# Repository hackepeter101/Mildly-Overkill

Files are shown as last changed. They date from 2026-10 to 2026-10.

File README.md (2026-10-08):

# Simple PLC-like Controller for Simple 24V Logic

## Specifications I am aiming for:

### Power & Protection
- 3S to 6S LiPo input support (including 24V)
- Onboard buck converter
- Reverse polarity protection
- Integrated fuse

### Motor Control
- 2x DC motor drivers (H-bridges)
- 3A current rating per bridge
- Current sensing at the H-bridges

### I/O & Interfaces
- Minimum of 8 total Inputs/Outputs (including H-bridge pins)
- STEMMA QT (I2C) connector
- USB-C port
- Physical Boot and Reset buttons

## Why
I have a project I need this for. I also did something similar for my day job and, to be honest, I wasn't entirely satisfied with my own work there—so this is my chance to improve on it.

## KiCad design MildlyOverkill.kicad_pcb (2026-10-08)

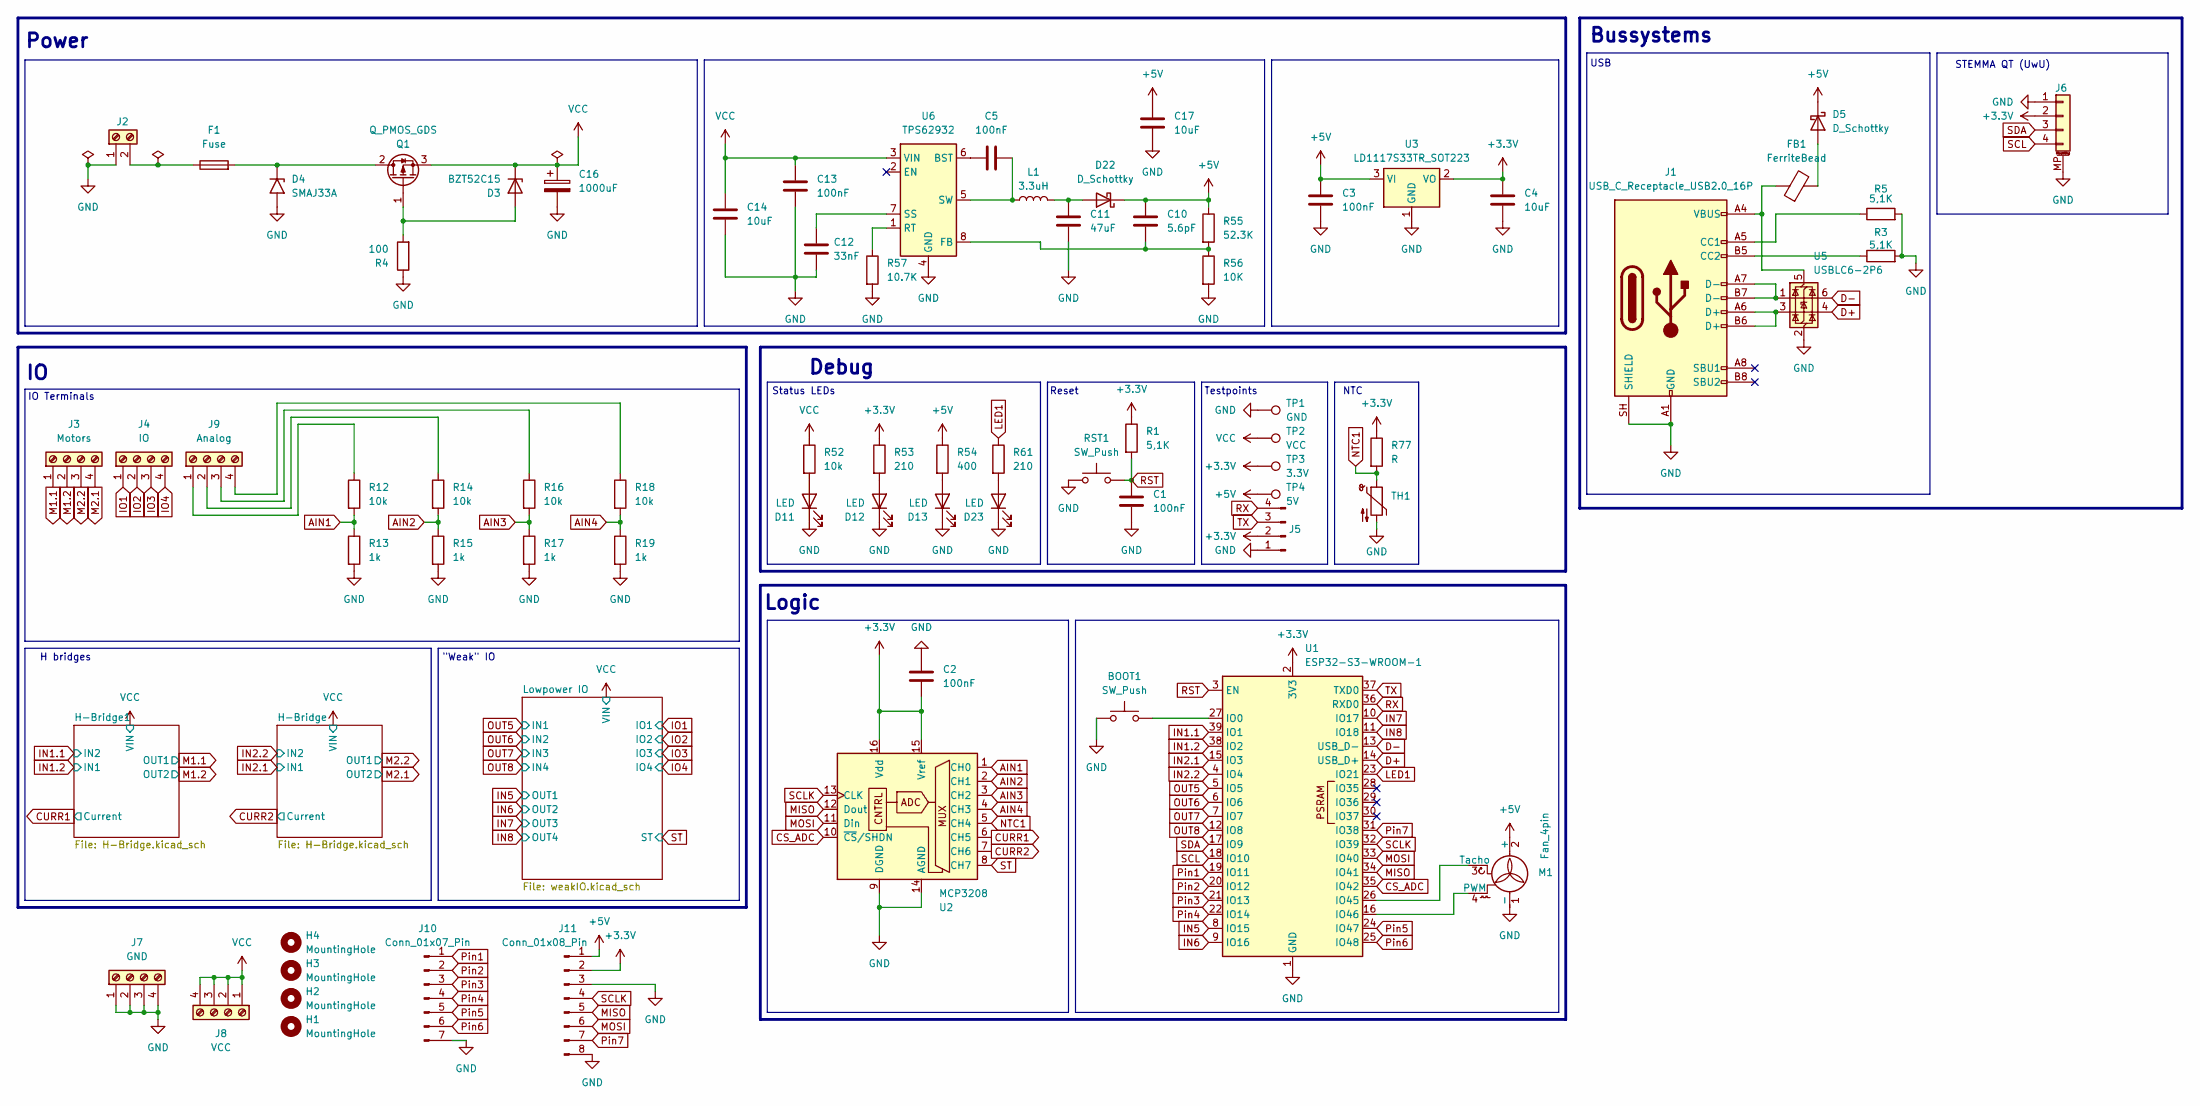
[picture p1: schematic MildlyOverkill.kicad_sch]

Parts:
BOOT1: SW_Push; SW_SPST_PTS647_Sx50
C1, C2, C3, C5, C13: 100nF; C_0603_1608Metric
C4: 10uF; C_1206_3216Metric
C10: 5.6pF; C_0603_1608Metric
C11: 47uF; C_0603_1608Metric
C12: 33nF; C_0603_1608Metric
C14: 10uF; C_1210_3225Metric
C16: 1000uF; CP_Radial_D16.0mm_P7.50mm
C17: 10uF; C_0603_1608Metric
D3: BZT52C15; D_0805_2012Metric
D4: SMAJ33A; D_SMA
D5, D22: D_Schottky; D_SOD-123
D11, D12, D13, D23: LED; LED_0603_1608Metric
F1: Fuse; Fuseholder_Blade_Mini_Keystone_3568
FB1: FerriteBead; L_0805_2012Metric
H1, H2, H3, H4: MountingHole; MountingHole_2.1mm
J1: USB_C_Receptacle_USB2.0_16P; USB_C_Receptacle_HRO_TYPE-C-31-M-12
J2: Screw_Terminal_01x02; PhoenixContact_MSTBA_2,5_2-G_1x02_P5.00mm_Horizontal
J3: Motors; TerminalBlock_Phoenix_MPT-0,5-4-2.54_1x04_P2.54mm_Horizontal
J4: IO; TerminalBlock_Phoenix_MPT-0,5-4-2.54_1x04_P2.54mm_Horizontal
J5: Conn_01x04_Pin; PinHeader_1x04_P2.54mm_Vertical
J6: Conn_01x04_MountingPin; JST_SH_BM04B-SRSS-TB_1x04-1MP_P1.00mm_Vertical
J7: GND; TerminalBlock_Phoenix_MPT-0,5-4-2.54_1x04_P2.54mm_Horizontal
J8: VCC; TerminalBlock_Phoenix_MPT-0,5-4-2.54_1x04_P2.54mm_Horizontal
J9: Analog; TerminalBlock_Phoenix_MPT-0,5-4-2.54_1x04_P2.54mm_Horizontal
J10: Conn_01x07_Pin; PinSocket_1x07_P2.54mm_Vertical
J11: Conn_01x08_Pin; PinSocket_1x08_P2.54mm_Vertical
L1: 3.3uH; WE-XHMI 4.3x4.3
M1: Fan_4pin; FanPinHeader_1x04_P2.54mm_Vertical
Q1: Q_PMOS_GDS; TO-252-2
R1, R3, R5: 5,1K; R_0603_1608Metric
R4: 100; R_0603_1608Metric
R12, R14, R16, R18, R52: 10k; R_0603_1608Metric
R13, R15, R17, R19: 1k; R_0603_1608Metric
R53, R61: 210; R_0603_1608Metric
R54: 400; R_0603_1608Metric
R55: 52.3K; R_0603_1608Metric
R56: 10K; R_0603_1608Metric
R57: 10.7K; R_0603_1608Metric
R77: R; R_0603_1608Metric
RST1: SW_Push; SW_SPST_PTS647_Sx50
TH1: Thermistor_NTC; R_0805_2012Metric_Pad1.20x1.40mm_HandSolder
TP1: GND; TestPoint_Loop_D2.50mm_Drill1.85mm
TP2: VCC; TestPoint_Loop_D2.50mm_Drill1.85mm
TP3: 3.3V; TestPoint_Loop_D2.50mm_Drill1.85mm
TP4: 5V; TestPoint_Loop_D2.50mm_Drill1.85mm
U1: ESP32-S3-WROOM-1
U2: MCP3208; SOIC-16_3.9x9.9mm_P1.27mm
U3: LD1117S33TR_SOT223; SOT-223-3_TabPin2
U5: USBLC6-2P6; SOT-666
U6: TPS62932; SOT-583-8

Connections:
+3.3V: C2.2, C4.1, J5.2, J6.2, J11.2, R1.1, R53.1, R77.1, TP3.1 (1_1), U1.2 (3V3), U2.15 (Vref), U2.16 (Vdd), U3.2 (VO); also elsewhere on the board
+5V: C3.1, C10.2, C17.2, D5.1 (K), D22.1 (K), J11.1, M1.2 (+), R54.1, R55.1, TP4.1 (1_1), U3.3 (VI)
AIN1: R12.2, R13.1, U2.1 (CH0)
AIN2: R14.2, R15.1, U2.2 (CH1)
AIN3: R16.2, R17.1, U2.3 (CH2)
AIN4: R18.2, R19.1, U2.4 (CH3)
CS_ADC: U1.35 (IO42), U2.10 (~CS/SHDN)
CURR1: U2.6 (CH5); also elsewhere on the board
CURR2: U2.7 (CH6); also elsewhere on the board
D+: U1.14 (USB_D+), U5.4 (I/O2)
D-: U1.13 (USB_D-), U5.6 (I/O1)
GND: BOOT1.1, C1.2, C2.1, C3.2, C4.2, C11.1, C12.1, C13.1, C14.1, C16.2, C17.1, D4.2 (A2), D11.1 (K), D12.1 (K), D13.1 (K), D23.1 (K), J1.A1 (GND), J1.A12 (GND), J1.B1 (GND), J1.B12 (GND), J1.SH (SHIELD), J2.1, J5.1, J6.1, J6.MP (MountPin), J7.1, J7.2, J7.3, J7.4, J10.7, J11.3, J11.8, M1.1 (-), R3.2, R4.1, R5.2, R13.2, R15.2, R17.2, R19.2, R56.2, R57.2, RST1.1, TH1.2, TP1.1 (1_1), U1.1 (GND), U1.40 (GND), U1.41 (GND), U2.9 (DGND), U2.14 (AGND), U3.1 (GND), U5.2 (GND), U6.4 (GND); also elsewhere on the board
IN1.1: U1.39 (IO1); also elsewhere on the board
IN1.2: U1.38 (IO2); also elsewhere on the board
IN2.1: U1.15 (IO3); also elsewhere on the board
IN2.2: U1.4 (IO4); also elsewhere on the board
IN5: U1.8 (IO15); also elsewhere on the board
IN6: U1.9 (IO16); also elsewhere on the board
IN7: U1.10 (IO17); also elsewhere on the board
IN8: U1.11 (IO18); also elsewhere on the board
IO1: J4.1; also elsewhere on the board
IO2: J4.2; also elsewhere on the board
IO3: J4.3; also elsewhere on the board
IO4: J4.4; also elsewhere on the board
LED1: R61.1, U1.23 (IO21)
M1.1: J3.1; also elsewhere on the board
M1.2: J3.2; also elsewhere on the board
M2.1: J3.4; also elsewhere on the board
M2.2: J3.3; also elsewhere on the board
MISO: J11.5, U1.34 (IO41), U2.12 (Dout)
MOSI: J11.6, U1.33 (IO40), U2.11 (Din)
NTC1: R77.2, TH1.1, U2.5 (CH4)
unnamed: D3.2 (A), Q1.1 (G), R4.2
unnamed: D4.1 (A1), F1.2, Q1.2 (D)
unnamed: D5.2 (A), FB1.2
unnamed: D11.2 (A), R52.2
unnamed: D12.2 (A), R53.2
unnamed: D13.2 (A), R54.2
unnamed: C11.2, D22.2 (A), L1.2
unnamed: D23.2 (A), R61.2
unnamed: J1.A5 (CC1), R5.1
unnamed: J1.B5 (CC2), R3.1
unnamed: J1.A6 (D+), J1.B6 (D+), U5.3 (I/O2)
unnamed: J1.A7 (D-), J1.B7 (D-), U5.1 (I/O1)
unnamed: F1.1, J2.2
unnamed: J9.1, R12.1
unnamed: J9.2, R14.1
unnamed: J9.3, R16.1
unnamed: J9.4, R18.1
unnamed: M1.4 (PWM), U1.16 (IO46)
unnamed: M1.3 (Tacho), U1.26 (IO45)
unnamed: BOOT1.2, U1.27 (IO0)
unnamed: FB1.1, J1.A4 (VBUS), J1.A9 (VBUS), J1.B4 (VBUS), J1.B9 (VBUS), U5.5 (VBUS)
unnamed: C5.1, U6.6 (BST)
unnamed: C10.1, R55.2, R56.1, U6.8 (FB)
unnamed: R57.1, U6.1 (RT)
unnamed: C12.2, U6.7 (SS)
unnamed: C5.2, L1.1, U6.5 (SW)
OUT5: U1.5 (IO5); also elsewhere on the board
OUT6: U1.6 (IO6); also elsewhere on the board
OUT7: U1.7 (IO7); also elsewhere on the board
OUT8: U1.12 (IO8); also elsewhere on the board
Pin1: J10.1, U1.19 (IO11)
Pin2: J10.2, U1.20 (IO12)
Pin3: J10.3, U1.21 (IO13)
Pin4: J10.4, U1.22 (IO14)
Pin5: J10.5, U1.24 (IO47)
Pin6: J10.6, U1.25 (IO48)
Pin7: J11.7, U1.31 (IO38)
RST: C1.1, R1.2, RST1.2, U1.3 (EN)
RX: J5.4, U1.36 (RXD0)
SCL: J6.4, U1.18 (IO10)
SCLK: J11.4, U1.32 (IO39), U2.13 (CLK)
SDA: J6.3, U1.17 (IO9)
ST: U2.8 (CH7); also elsewhere on the board
TX: J5.3, U1.37 (TXD0)
VCC: C13.2, C14.2, C16.1, D3.1 (K), J8.1, J8.2, J8.3, J8.4, Q1.3 (S), R52.1, TP2.1 (1_1), U6.3 (VIN); also elsewhere on the board

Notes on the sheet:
H bridges
Debug
IO Terminals
Power
Reset
NTC
Logic
Testpoints
STEMMA QT (UwU)
Bussystems
"Weak" IO
USB
Status LEDs

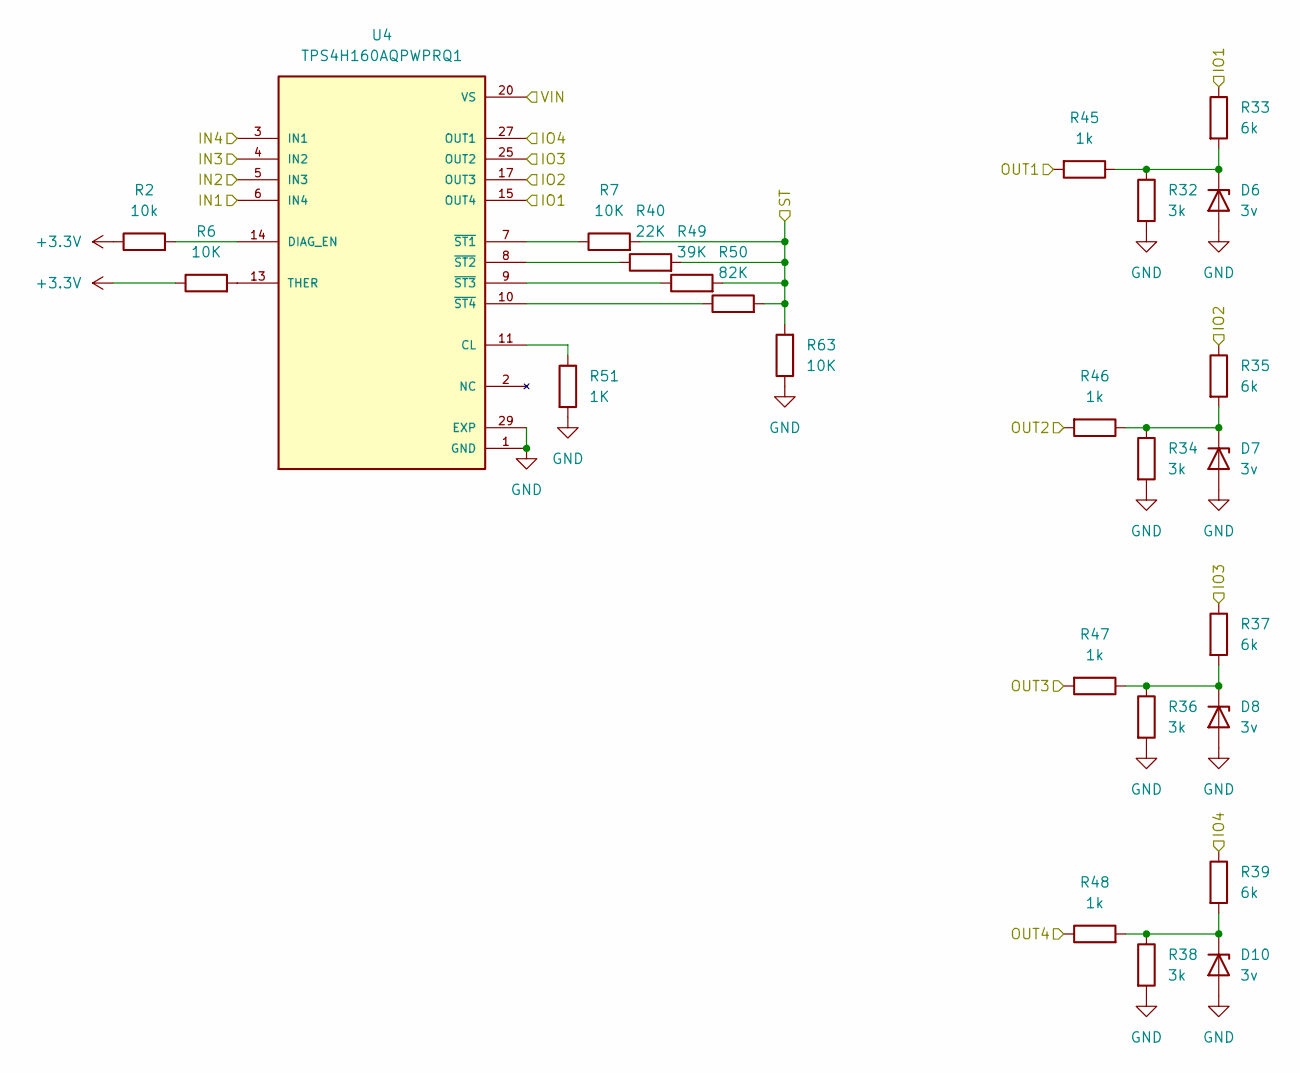
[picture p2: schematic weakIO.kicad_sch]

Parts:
D6, D7, D8, D10: 3v; D_0603_1608Metric
R2: 10k; R_0603_1608Metric
R6, R7, R63: 10K; R_0603_1608Metric
R32, R34, R36, R38: 3k; R_0603_1608Metric
R33, R35, R37, R39: 6k; R_0603_1608Metric
R40: 22K; R_0603_1608Metric
R45, R46, R47, R48: 1k; R_0603_1608Metric
R49: 39K; R_0603_1608Metric
R50: 82K; R_0603_1608Metric
R51: 1K; R_0603_1608Metric
U4: TPS4H160AQPWPRQ1; IC_TPS4H160AQPWPRQ1; PARTREV D

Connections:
+3.3V: R2.1, R6.1; also elsewhere on the board
GND: D6.2 (A), D7.2 (A), D8.2 (A), D10.2 (A), R32.2, R34.2, R36.2, R38.2, R51.2, R63.1, U4.1 (GND), U4.12 (GND), U4.29 (EXP), U4.30 (EXP), U4.31 (EXP), U4.32 (EXP), U4.33 (EXP), U4.34 (EXP), U4.35 (EXP), U4.36 (EXP), U4.37 (EXP), U4.38 (EXP), U4.39 (EXP), U4.40 (EXP), U4.41 (EXP), U4.42 (EXP), U4.43 (EXP), U4.44 (EXP), U4.45 (EXP), U4.46 (EXP), U4.47 (EXP), U4.48 (EXP), U4.49 (EXP), U4.50 (EXP), U4.51 (EXP), U4.52 (EXP), U4.53 (EXP); also elsewhere on the board
IN5: R45.2; also elsewhere on the board
IN6: R46.2; also elsewhere on the board
IN7: R47.2; also elsewhere on the board
IN8: R48.1; also elsewhere on the board
IO1: R33.1, U4.15 (OUT4), U4.16 (OUT4); also elsewhere on the board
IO2: R35.1, U4.17 (OUT3), U4.18 (OUT3); also elsewhere on the board
IO3: R37.1, U4.25 (OUT2), U4.26 (OUT2); also elsewhere on the board
IO4: R39.1, U4.27 (OUT1), U4.28 (OUT1); also elsewhere on the board
unnamed: D6.1 (K), R32.1, R33.2, R45.1
unnamed: D7.1 (K), R34.1, R35.2, R46.1
unnamed: D8.1 (K), R36.1, R37.2, R47.1
unnamed: D10.1 (K), R38.1, R39.2, R48.2
unnamed: R51.1, U4.11 (CL)
unnamed: R2.2, U4.14 (DIAG_EN)
unnamed: R6.2, U4.13 (THER)
unnamed: R7.1, U4.7 (~ST1)
unnamed: R40.1, U4.8 (~ST2)
unnamed: R49.1, U4.9 (~ST3)
unnamed: R50.1, U4.10 (~ST4)
OUT5: U4.6 (IN4); also elsewhere on the board
OUT6: U4.5 (IN3); also elsewhere on the board
OUT7: U4.4 (IN2); also elsewhere on the board
OUT8: U4.3 (IN1); also elsewhere on the board
ST: R7.2, R40.2, R49.2, R50.2, R63.2; also elsewhere on the board
VCC: U4.20 (VS), U4.21 (VS), U4.22 (VS), U4.23 (VS); also elsewhere on the board

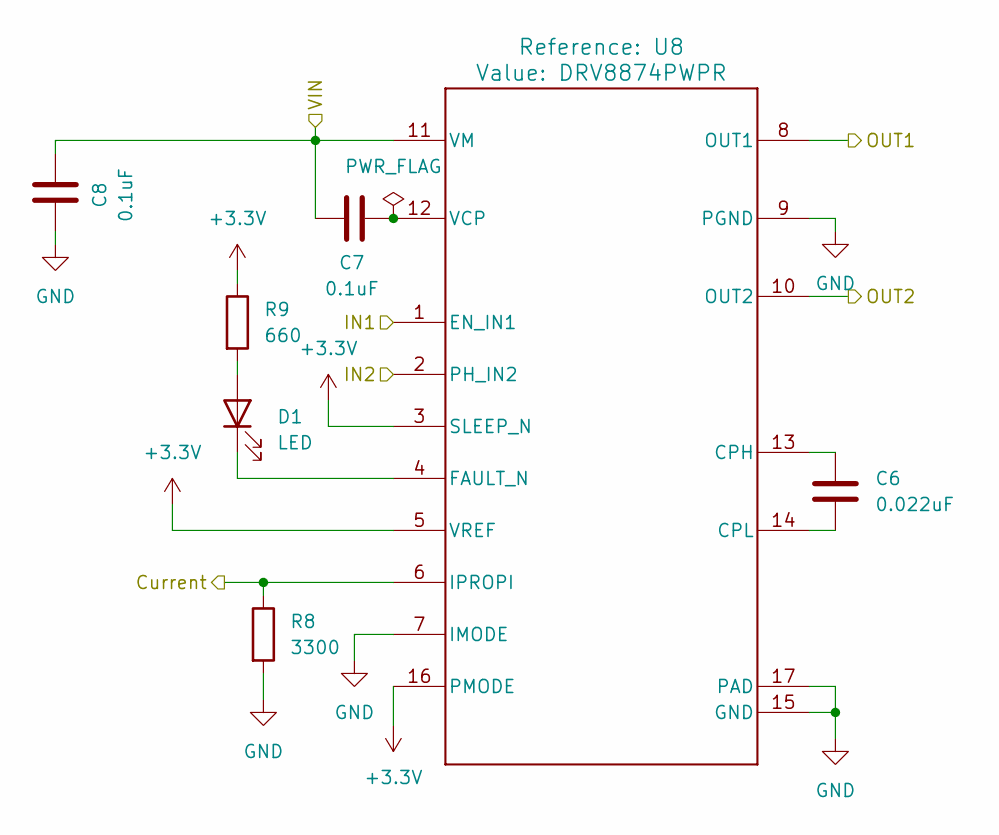
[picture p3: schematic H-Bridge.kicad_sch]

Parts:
C6: 0.022uF; C_0603_1608Metric
C7, C8: 0.1uF; C_0603_1608Metric
D1: LED; LED_0603_1608Metric
R8: 3300; R_0603_1608Metric
R9: 660; R_0603_1608Metric
U8: DRV8874PWPR; PWP0016J_L

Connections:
+3.3V: R9.1, U8.3 (SLEEP_N), U8.5 (VREF), U8.16 (PMODE); also elsewhere on the board
CURR2: R8.1, U8.6 (IPROPI); also elsewhere on the board
GND: C8.1, R8.2, U8.7 (IMODE), U8.9 (PGND), U8.15 (GND), U8.17 (PAD); also elsewhere on the board
IN2.1: U8.1 (EN_IN1); also elsewhere on the board
IN2.2: U8.2 (PH_IN2); also elsewhere on the board
M2.1: U8.10 (OUT2); also elsewhere on the board
M2.2: U8.8 (OUT1); also elsewhere on the board
unnamed: D1.2 (A), R9.2
unnamed: D1.1 (K), U8.4 (FAULT_N)
unnamed: C6.1, U8.13 (CPH)
unnamed: C6.2, U8.14 (CPL)
unnamed: C7.2, U8.12 (VCP)
VCC: C7.1, C8.2, U8.11 (VM); also elsewhere on the board

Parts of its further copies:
C9, C15: 0.1uF; C_0603_1608Metric
C18: 0.022uF; C_0603_1608Metric
D2: LED; LED_0603_1608Metric
R10: 660; R_0603_1608Metric
R11: 3300; R_0603_1608Metric
U9: DRV8874PWPR; PWP0016J_L

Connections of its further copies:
+3.3V: R10.1, U9.3 (SLEEP_N), U9.5 (VREF), U9.16 (PMODE); also elsewhere on the board
CURR1: R11.1, U9.6 (IPROPI); also elsewhere on the board
GND: C9.1, R11.2, U9.7 (IMODE), U9.9 (PGND), U9.15 (GND), U9.17 (PAD); also elsewhere on the board
IN1.1: U9.2 (PH_IN2); also elsewhere on the board
IN1.2: U9.1 (EN_IN1); also elsewhere on the board
M1.1: U9.8 (OUT1); also elsewhere on the board
M1.2: U9.10 (OUT2); also elsewhere on the board
unnamed: D2.2 (A), R10.2
unnamed: D2.1 (K), U9.4 (FAULT_N)
unnamed: C18.1, U9.13 (CPH)
unnamed: C18.2, U9.14 (CPL)
unnamed: C15.2, U9.12 (VCP)
VCC: C9.2, C15.1, U9.11 (VM); also elsewhere on the board

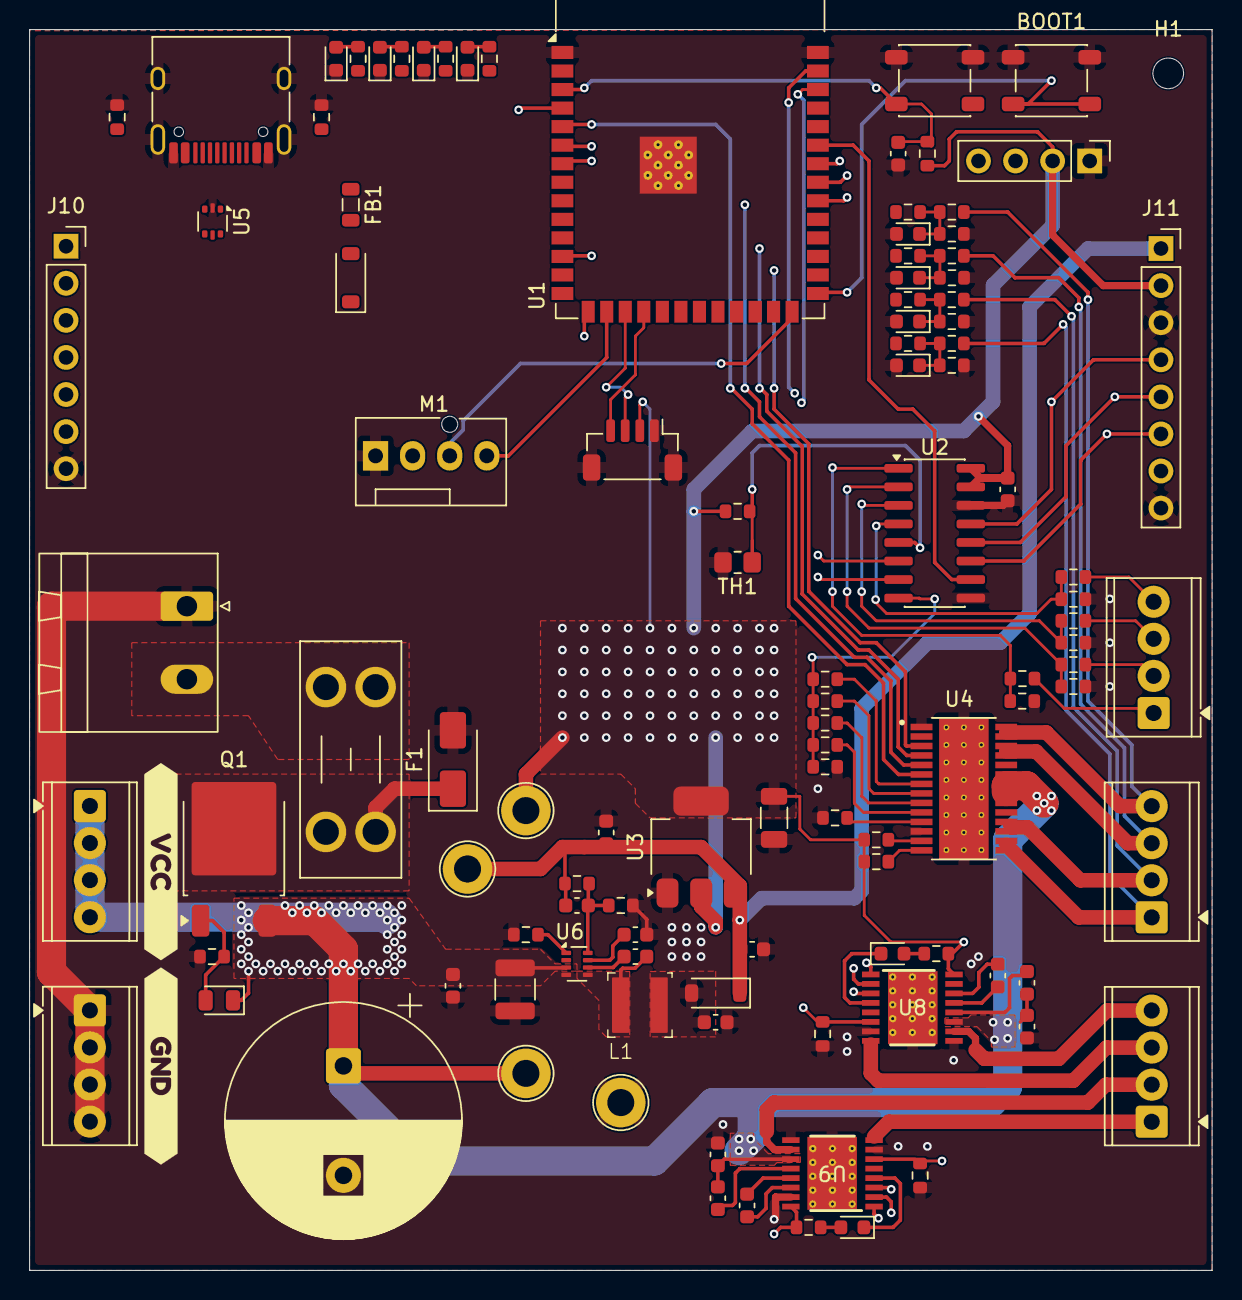
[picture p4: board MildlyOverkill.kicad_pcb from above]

Board: 4 copper layers, 81.0 x 85.0 mm, 113 parts (0 on the bottom side), 98 nets.

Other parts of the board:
kibuzzard-6AC244AE: G***; kibuzzard-6AC244AE
kibuzzard-6AC244BE: G***; kibuzzard-6AC244BE

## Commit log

2026-09-15 started routing
    [HighPowerOut.kicad_sch, MildlyOverkill.kicad_pcb, MildlyOverkill.kicad_sch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]
2026-09-17 Added ethernet and ntcs
    [MildlyOverkill.kicad_pcb, MildlyOverkill.kicad_sch, PowerIO.kicad_sch]
2026-09-20 kinda finished high power i guess
    [MildlyOverkill.kicad_pcb, MildlyOverkill.kicad_sch, weakIO.kicad_sch]
2026-09-20 updated gitignore, ainteractive BOM and not much else
    [MildlyOverkill.kicad_pcb, MildlyOverkill.kicad_sch, PowerIO.kicad_sch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]
2026-09-22 routed ethernet
    [MildlyOverkill.kicad_pcb, MildlyOverkill.kicad_sch]
2026-09-23 idk tbh
    [MildlyOverkill.kicad_pcb]
2026-09-23 New refactor into a Smaler formfactor (2 Layer Possible?)
    [H-Bridge.kicad_sch, HighPowerOut.kicad_sch, MildlyOverkill.kicad_pcb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]
2026-09-23 fixed BOM
2026-09-24 Added custom footprint and made Buck samller
    [MildlyOverkill.kicad_pcb, MildlyOverkill.kicad_sch]
2026-09-25 H-Bridges are done i guess
    [MildlyOverkill.kicad_pcb, MildlyOverkill.kicad_sch, weakIO.kicad_sch]
2026-09-25 Power stage almost done
    [MildlyOverkill.kicad_pcb, MildlyOverkill.kicad_sch]
2026-09-27 Insane amounts of routing and Ethernet ist basicaly done.
    DRC is going to be fun for future me...
    [MildlyOverkill.kicad_pcb, MildlyOverkill.kicad_sch]
2026-10-07 idk where to begin...
    [H-Bridge.kicad_sch, MildlyOverkill.kicad_pcb, MildlyOverkill.kicad_sch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]
2026-10-08 I cant do this anymore
    [MildlyOverkill.kicad_pcb, MildlyOverkill.kicad_sch]
2026-10-13 BOM cleanup: values, MPNs and voltage ratings from todo.md
    Values/fields only, no footprint or net changes (netlist diff is empty).
2026-10-13 todo: switch U3 to GND-tab AP7361C-33E-13
2026-10-13 todo: end-of-day status, tick PWR_FLAG, add U3 tab GND vias
